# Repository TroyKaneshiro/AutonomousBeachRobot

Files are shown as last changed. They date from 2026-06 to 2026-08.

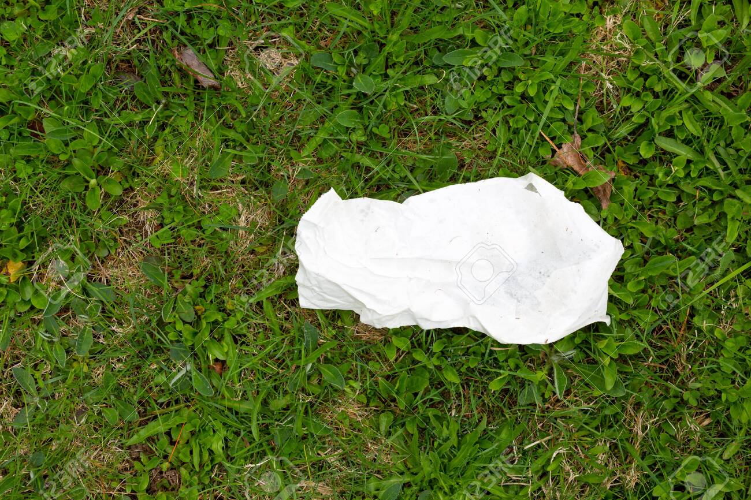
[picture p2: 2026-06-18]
tools/test_trash2.jpg

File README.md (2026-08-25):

# Autonomous Beach Robot

Perception-driven outdoor mobile robot that autonomously detects, tracks, and approaches litter using computer vision and a reactive finite state machine.

Built from scratch with ROS 2 Jazzy, micro-ROS, and custom motor control firmware split across a Raspberry Pi 5 (intelligence) and ESP32 (real-time motor control).

**Current status:** Visual servoing and full FSM state transitions working on hardware. Chassis integration and physical collection mechanism in progress.  
**V2 goal:** Physical trash collection via scoop mechanism, more robust chasis in progress.

---

## System Architecture

### Compute split

| Platform | Role |
|---|---|
| Raspberry Pi 5 (4GB) | ROS 2 Jazzy, YOLOv8n inference, CSRT tracking, mission FSM, GPS logging |
| ESP32 (micro-ROS) | PID motor control at 100Hz on Core 1; encoder odometry on Core 0 |

The Pi decides what to do. The ESP32 executes it with no OS jitter.

### ROS 2 node graph

```
/camera/image_raw ──┬──▶ trash_detector ──▶ /trash_detections ──▶ mission_fsm ──▶ /cmd_vel ──▶ ESP32
                    └──▶ terrain_monitor ──▶ /terrain_events   ──▶ mission_fsm
/wheel/odometry ────────────────────────────────────────────────────────────────▶ mission_fsm
/imu/data ──────────────────────────────────────────────────────────────────────▶ terrain_monitor
/fix (GPS) ──────────────────────────────────────────────────────────────────────▶ mission_fsm
                                                          coordinator ───────────▶ /e_stop ──▶ ESP32
```

---

## Perception Pipeline

**YOLO + CSRT hybrid** — balances detection accuracy with compute budget on Pi 5:

- YOLOv8n runs at ~10 FPS for detection and target selection
- CSRT correlation filter tracks at 30+ FPS between YOLO cycles
- When CSRT loses the target, YOLO re-acquires on the next cycle

**Target scoring** when multiple detections exist:

```python
score = (0.7 * normalised_bbox_area) + (0.3 * confidence)
```

Proximity-weighted: closest target preferred, confidence as tiebreaker.

**Model:** YOLOv8n fine-tuned on [TACO dataset](http://tacodataset.org/) (Trash Annotations in Context), single class `trash`. ONNX export for CPU inference. Current validation **mAP50: 0.549**.

---

## Navigation

**Visual servoing** — no depth sensor, no coordinate transforms:

```python
pixel_error = bbox_centre_x - frame_width / 2
angular_z   = -Kp * pixel_error    # Kp ≈ 0.002
linear_x    = 0.2                  # m/s approach speed
```

Distance inferred from bounding box area growth. Calibrate `pickup_area_threshold` once at physical pickup distance.

**Terrain safety — three independent layers:**

| Layer | Sensor | Detects | Blind spots |
|---|---|---|---|
| Primary | Camera HSV (bottom ⅓ of frame) | Sand→grass, sand→pavement boundaries | Dropoffs, night, glare |
| Backstop | MPU-6050 IMU (pitch + variance) | Dropoffs, vibration spikes, soft sand | Gradual colour-only transitions |
| Backstop | ACS712 current sensors | Motor stall, high-resistance terrain | Airborne obstacles |

---

## Mission FSM

| State | Entry | Behaviour | Exit |
|---|---|---|---|
| CALIBRATE | Startup | Hold still 1.5s; IMU baseline lock | Baseline set → SCAN |
| SCAN | Post-calibrate / post-flag | Rotate 0.3 rad/s; YOLO every 0.5s | Detection conf ≥ 0.45 → TRACK |
| TRACK | Detection acquired | CSRT tracking + visual servoing forward | bbox area ≥ threshold → PICKUP; timeout → SCAN |
| PICKUP | Close enough | V1: log GPS + confidence to CSV, reset tracker. V2: actuate collection mechanism | Complete → SCAN |
| STUCK | No odometry movement for 5s despite cmd_vel | Reverse 0.3m, rotate 45°, resume prior state | Movement detected → prior state |
| LOW_BATTERY | Voltage < 10.5V (3S cutoff) | Stop all motion | Manual operator reset |

---

## ESP32 Firmware

The ESP32 runs custom firmware with:

- **PID motor control at 100Hz** on Core 1 — differential drive kinematics, closed-loop velocity control from encoder feedback
- **micro-ROS bridge** on Core 0 — subscribes to `/cmd_vel` and `/e_stop`, publishes `/wheel/odometry` and `/motor_events`
- **Safety watchdog** — automatically stops motors if no `/cmd_vel` received for 1 second
- **Quadrature encoder odometry** — left and right wheel position and velocity

### Pin assignments

| Signal | GPIO |
|---|---|
| Left Motor PWM | 25 |
| Left Motor DIR | 26 |
| Right Motor PWM | 27 |
| Right Motor DIR | 14 |
| Left Encoder A | 32 |
| Left Encoder B | 33 |
| Right Encoder A | 23 |
| Right Encoder B | 22 |

---

## Hardware Stack

| Component | Role |
|---|---|
| Raspberry Pi 5 (4GB) | Main compute |
| ESP32 DevKit C | Real-time motor control, micro-ROS |
| Cytron MDD10A | Dual motor driver (10A/ch, 3.3V logic native) |
| 4× 12V DC gear motors w/ encoders (JGA25-370) | Locomotion + odometry |
| HD USB Webcam | Trash detection + terrain classification |
| MPU-6050 IMU | Terrain safety |
| u-blox NEO-M8N GPS | Detection coordinate logging |
| ACS712 30A ×2 | Per-motor current sensing |
| 3S LiPo 5000mAh | Main power |

---

## Repository Structure

```
ros2_ws/src/
├── perception/           # trash_detector (YOLO+CSRT) and terrain_monitor nodes
├── v1_navigator/         # mission_fsm — 6-state FSM, visual servoing, GPS CSV logging
├── mission_control/      # coordinator — operator interface, e-stop, 1Hz telemetry
└── robot_bringup/        # launch files and robot_params.yaml

esp32/
└── src/main.cpp          # ESP32 firmware — PID motor control + micro-ROS

ml/
├── convert.py            # TACO COCO→YOLO format converter (80/20 train/val split)
├── trash.yaml            # YOLOv8 dataset config
└── models/               # Trained ONNX weights (Git LFS)

tools/
├── fake_camera.py        # Publishes static image as /camera/image_raw at 30fps
├── fake_hardware.py      # Stubs /wheel/odometry, /imu/data, /fix, /battery_voltage
├── stream_camera.py      # MJPEG HTTP stream for viewing camera feed over network
└── model_tester.py       # Standalone YOLO inference check without ROS

docs/
└── beach_robot_spec_v2.md  # Full system specification with V2 plans
```

---

## Hardware-less Simulation

The full ROS 2 pipeline runs without physical hardware:

```bash
# Terminal 1 — launch in sim mode
ros2 launch robot_bringup sim.launch.py image_path:=/path/to/trash.jpg

# Terminal 2 — arm the robot
ros2 topic pub --once /mission_control/command std_msgs/msg/String "data: START"

# Monitor state
ros2 topic echo /mission_status

# Emergency stop
ros2 topic pub --once /mission_control/command std_msgs/msg/String "data: STOP"
```

---

## Live Camera Stream

To view the camera feed over the network during field testing:

```bash
python3 tools/stream_camera.py
```

Open `http://beachrobot.local:8080` in a browser. Displays live feed with detection bounding boxes overlaid.

---

## V1 vs V2

| Feature | V1 — current | V2 — planned |
|---|---|---|
| Navigation | Reactive visual servoing | Nav2 + EKF + GPS area coverage |
| Detection | YOLOv8n + CSRT | Same, improved dataset |
| Distance | Bounding box area heuristic | Monocular depth or OAK-D stereo |
| Collection | GPS coordinate logging | Servo gripper arm or scoop mechanism |
| Coverage | Scan-navigate-scan | Lawnmower path planning |

---

## Known Limitations

- CSRT tracker loses target under fast motion or significant viewpoint change — re-acquired by YOLO on next cycle
- Confidence threshold (0.45) tuned for outdoor daylight — performance degrades in low light
- Single encoder odometry on current breadboard build — both encoders to be added on perfboard
- No ROS timestamp sync on ESP32 in current build — STUCK watchdog uses position delta rather than message age

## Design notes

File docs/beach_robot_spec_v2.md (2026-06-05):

  
**Beach Trash Collection Robot**

Project Specification  ·  v2

EE/CS \+ MechE/ECE  ·  Summer Build

*Autonomous outdoor robot that scans for litter, tracks and approaches the highest-priority target, and logs GPS coordinates for collection — with a robotic arm pickup system as the v2 goal.*

# **1\. Project overview**

This robot patrols a beach or open field autonomously, uses computer vision to detect and track litter, and drives toward the highest-priority piece of trash. V1 logs GPS coordinates of detections. V2 adds a robotic arm for physical collection.

## **1.1 Core behaviour loop**

* SCAN — robot rotates 360°, YOLOv8n identifies all visible trash, scores each detection by proximity and confidence

* TRACK — CSRT visual tracker locks onto the best target, robot steers toward it using visual servoing

* APPROACH — bounding box area grows as robot closes in; no explicit distance measurement needed

* FLAG / PICKUP — at threshold bbox size: V1 logs GPS coordinate; V2 actuates gripper arm

* SCAN again — repeat until battery low or operator stop

*Design principle: the robot is perception-driven — every movement decision comes from what the camera sees, not a pre-planned path. This makes behaviour more robust and the project significantly more impressive as a portfolio piece.*

## **1.2 V1 vs V2 scope**

| Feature | V1 — ship by end of summer | V2 — stretch / fall |
| :---- | :---- | :---- |
| Navigation | Reactive — IMU \+ camera terrain boundary | Nav2 \+ EKF \+ GPS positioning |
| Target detection | YOLOv8n scan \+ CSRT tracking | Same, improved dataset |
| Distance sensing | Bounding box area heuristic | Monocular depth or OAK-D |
| Trash collection | GPS flag and log | Servo gripper arm pickup |
| Coverage | Scan-navigate-scan | Lawnmower path planning |
| Localisation | None required | Odometry \+ IMU \+ GPS EKF fusion |

# **2\. Team & responsibility split**

| Domain | EE/CS | MechE/ECE partner |
| :---- | :---- | :---- |
| Chassis & drivetrain | — | CAD design, 3D-printed mounts, assembly |
| Motor control firmware | Serial protocol, ROS bridge | PID loop on ESP32 |
| Power system | Wiring, buck converter, fusing, LiPo safety | Cable routing through chassis |
| Sensors | IMU, GPS, camera wiring and drivers | Encoder wiring, current sensor placement |
| Perception | YOLOv8 training, CSRT node, terrain classifier | Camera mounting, FOV optimisation |
| Navigation FSM | Mission state machine, visual servoing | Odometry calibration, field testing |
| Integration | ROS node graph, launch files, logging | Mechanical fixes, sand-proofing |
| V2 arm (stretch) | PCA9685 servo driver, arm ROS node | Gripper mechanism design and fabrication |

# **3\. System architecture**

## **3.1 Hardware layers**

The system is split across two compute platforms with a clean interface between them.

| Layer | Hardware | Responsibility |
| :---- | :---- | :---- |
| Brain | Raspberry Pi 5 (4GB) | ROS 2, YOLOv8 inference, CSRT tracker, mission FSM, GPS logging |
| Muscles | ESP32 DevKit C | PID motor control at 100Hz, encoder counting, current sensing, micro-ROS bridge |
| Drive | Cytron MDD10A \+ 4× 12V DC gear motors | Locomotion — converts PWM signals to motor power |
| Vision | Pi Camera Module 3 (wide angle) | Single shared feed for trash detection and terrain classification |
| Orientation | MPU-6050 IMU | Safety layer — pitch and vibration spike detection for terrain boundaries and dropoffs |
| Location | u-blox NEO-M8N GPS | Logs coordinates of every detected trash item at 5Hz |
| Current sense | ACS712 30A ×2 | Per-motor current monitoring — detects stall and terrain resistance changes |
| Power | 3S LiPo 5000mAh \+ buck converter 12V→5V | Isolated rails for motors and compute; LiPo alarm on balance lead |
| V2: Arm driver | PCA9685 servo driver board | Controls gripper arm servos from Pi over I2C |

## **3.2 ROS 2 topic map**

| Topic | Message type | Publisher | Subscriber(s) |
| :---- | :---- | :---- | :---- |
| /camera/image\_raw | sensor\_msgs/Image | v4l2\_camera\_node | perception, terrain\_monitor |
| /trash\_detections | std\_msgs/String | trash\_detector | mission\_fsm |
| /terrain\_events | std\_msgs/String | terrain\_monitor | mission\_fsm |
| /motor\_events | std\_msgs/String | ESP32 | mission\_fsm |
| /cmd\_vel | geometry\_msgs/Twist | mission\_fsm / navigator | ESP32 |
| /wheel/odometry | nav\_msgs/Odometry | ESP32 | mission\_fsm (V2: EKF) |
| /imu/data | sensor\_msgs/Imu | mpu6050\_driver | terrain\_monitor |
| /fix | sensor\_msgs/NavSatFix | ublox\_gps\_node | gps\_logger |
| /battery\_voltage | std\_msgs/Float32 | ESP32 | mission\_fsm |

## **3.3 Mission FSM**

All navigation and task behaviour lives in a single finite state machine node. States are mutually exclusive; transitions are event-driven.

| State | Entry condition | Behaviour | Exit condition |
| :---- | :---- | :---- | :---- |
| CALIBRATE | Startup | Hold still, establish IMU baseline variance over 1.5s | Baseline locked → SCAN |
| SCAN | After CALIBRATE, FLAG, or PICKUP | Rotate slowly at 0.3 rad/s, run YOLO every 0.5s, score all detections | Detection above threshold → TRACK |
| TRACK | Detection scored and selected | CSRT locks on target, visual servoing steers robot toward it | Bbox area \> threshold → PICKUP; target lost → SCAN |
| PICKUP / FLAG | Close enough to target | V1: log GPS \+ confidence to CSV. V2: stop, actuate arm | Attempt complete → SCAN |
| STUCK | No movement for 5s despite cmd\_vel | Reverse 0.3m, rotate 45°, resume prior state | Movement detected → resume |
| LOW\_BATTERY | Voltage \< 10.5V (3S cutoff) | Stop all motion, publish alert, await operator | Manual reset only |

# **4\. Perception pipeline**

## **4.1 Trash detection — YOLOv8n**

* Model: YOLOv8 nano (yolov8n.pt), fine-tuned on TACO dataset (Trash Annotations in Context)

* Classes: collapsed to single class 'trash' for v1 — simplifies training, sufficient for detection

* Export format: ONNX, imgsz=640, simplified

* Target inference rate: 8–15 FPS on Pi 5 with active cooling

* Target mAP50: \> 0.40 on validation set

## **4.2 Target selection scoring**

When multiple detections exist, a weighted score selects the best target per frame:

score \= (0.7 × normalised\_bbox\_area) \+ (0.3 × confidence)

* Proximity weight 0.7 — closest target preferred; bbox area is proxy for distance

* Confidence weight 0.3 — avoids wasting approach on false positives

* Blacklist — targets that fail pickup twice are excluded from scoring until next full scan

* Re-score every 2s during TRACK — relative distances change as robot moves

## **4.3 CSRT visual tracking**

After YOLO selects a target, a CSRT tracker (OpenCV built-in) takes over for per-frame localisation. YOLO runs at 8–10 FPS; CSRT runs at 30+ FPS on the same detection region without re-running the neural net.

* Init: tracker.init(frame, bbox) called once after YOLO detection

* Update: ok, bbox \= tracker.update(frame) every frame

* Lost: if ok is False → fall back to SCAN state to re-acquire

* Proximity trigger: bbox\_area / frame\_area \> PICKUP\_THRESHOLD (calibrate at your actual pickup distance)

## **4.4 Terrain classification**

A lightweight secondary perception node subscribes to the same camera feed and publishes STOP\_CAM events when the terrain ahead changes. The camera is a secondary signal; the IMU is the safety backstop.

* Method: HSV colour thresholding on bottom third of frame

* Trigger: sand\_ratio \< 0.5 in the ROI

* Rate: throttled to 10 FPS to leave headroom for YOLO

* Tuning: HSV range must be calibrated at the actual test location in the actual lighting conditions

*Camera terrain classification catches visual boundaries (sand/grass, sand/pavement). IMU catches physical events (dropoffs, vibration spikes, soft sand sinking). They fail on different inputs — both are needed.*

# **5\. Navigation & motor control**

## **5.1 Visual servoing**

The robot steers toward a tracked target using proportional control on the horizontal offset of the bounding box centre from the frame centre. No distance measurement, no coordinate frame transformation needed.

error \= bbox\_centre\_x − frame\_width/2angular\_z \= −Kp × error   (Kp ≈ 0.002, tune empirically)linear\_x \= APPROACH\_SPEED (0.2 m/s)

## **5.2 Motor control (ESP32)**

* PID loop runs at 100Hz on ESP32 Core 1 — real-time, no OS jitter

* Core 0 handles micro-ROS WiFi/serial comms — physically isolated from PID

* Per-motor PID — each motor has independent Kp/Ki/Kd; motors are never identical

* ACS712 current sensors publish HIGH\_CURRENT events when average exceeds 2.5A per motor

* Encoder odometry published to /wheel/odometry at 50Hz

## **5.3 Terrain safety — dual-layer**

| Layer | Sensor | Catches | Misses |
| :---- | :---- | :---- | :---- |
| Primary | Camera HSV classifier | Visual boundaries: sand→grass, sand→pavement | Dropoffs, soft sand, glare, night |
| Safety backstop | MPU-6050 IMU | Dropoffs, vibration spikes, pitch \> 8.5°, soft sand sinking | Gradual colour-only boundaries |
| Safety backstop | ACS712 current sensors | Motor stall, high resistance terrain, wheel sinking | Airborne obstacles, visual changes |

# **6\. Hardware bill of materials**

## **6.1 Compute & firmware**

| Component | Purpose | Cost | Notes |
| :---- | :---- | :---- | :---- |
| Raspberry Pi 5 (4GB) | Main compute, ROS 2, inference | $60 | Order immediately — can be backordered |
| Pi 5 active cooler | Thermal management under inference load | $5 | Required — YOLOv8 will throttle without it |
| ESP32 DevKit C ×2 | Real-time motor PID, micro-ROS | $16 | Buy two — one will get bricked in dev |
| MicroSD 64GB A2-rated | Pi OS \+ ROS workspace \+ rosbag logs | $10 | A2 speed class required for ROS I/O |

## **6.2 Chassis & drivetrain**

| Component | Purpose | Cost | Notes |
| :---- | :---- | :---- | :---- |
| 4WD aluminium chassis kit | Frame, mounts, hubs | $45 | Get one that includes motors \+ encoders |
| 12V DC gear motors ×4 with encoders | Locomotion \+ odometry feedback | Included | Verify \> 200 CPR encoder resolution |
| Wide rubber wheels ×4 | Traction on sand and grass | Included | Wide profile preferred; avoid narrow plastic |
| M3/M4 hardware assortment | Electronics mounting | $8 | Standoffs, screws, nuts — use everything |

## **6.3 Motor driver**

| Component | Purpose | Cost | Notes |
| :---- | :---- | :---- | :---- |
| Cytron MDD10A (recommended) | Dual motor driver, 10A/ch, 3.3V safe | $25 | MOSFET-based, no heatsink, ESP32 native logic |
| L298N (budget alternative) | Dual motor driver, 2A/ch | $4 | Add heatsink \+ logic level shifter; buy 2 as spares |
| Logic level shifter (if L298N) | 3.3V→5V for ESP32→L298N | $1 | Only needed with L298N |

## **6.4 Sensors**

| Component | Purpose | Cost | Notes |
| :---- | :---- | :---- | :---- |
| Pi Camera Module 3 Wide | Trash detection \+ terrain classifier | $25 | Wide angle; order immediately with Pi |
| MPU-6050 IMU | Terrain safety: pitch, vibration spike | $5 | Mount on 1mm foam tape away from motors |
| ACS712 30A current sensors ×2 | Per-motor stall and terrain detection | $6 | Inline with each motor lead |
| u-blox NEO-M8N GPS | Logs trash detection coordinates | $30 | Configure at 5Hz via u-center before deployment |
| Camera mount / articulating arm | Positions camera \~30° down at 0.5m | $8 | Can 3D print a custom mount |

## **6.5 Power system**

| Component | Purpose | Cost | Notes |
| :---- | :---- | :---- | :---- |
| 3S LiPo 5000mAh (Tattu / Gens Ace) | Main power source | $35 | Quality brand only; check C-rating ≥ 20C |
| LiPo battery alarm | Per-cell undervoltage alert at 3.5V | $3 | Non-negotiable safety item |
| LiPo balance charger (ISDT Q6) | Safe balanced charging | $25 | Never charge without a balance charger |
| LiPo safe bag | Fire containment during charging | $8 | Always charge in this bag |
| Buck converter 12V→5V 5A | Regulated 5V for Pi and sensors | $8 | Pololu D24V50F5 is reliable; verify 5.1V output |
| XT60 connector pairs ×5 | Battery main lead | $6 | Standard 60A+ rated; solder properly |
| 20A blade fuse \+ holder | Main line protection | $4 | Inline on battery positive; saves the chassis |

## **6.6 Wiring & consumables**

| Component | Purpose | Cost |
| :---- | :---- | :---- |
| Silicone wire 18AWG red/black 5m ea | Motor and power runs | $10 |
| Jumper wire kit (M-M, M-F, F-F) | Sensor connections and prototyping | $7 |
| JST-XH 2.54mm connector kit | Encoder and sensor wire management | $8 |
| Heat shrink tubing assortment | Insulation on all solder joints | $5 |
| 1mm foam mounting tape | IMU vibration damping | $4 |
| Velcro straps | Battery retention and cable routing | $5 |
| Conformal coat spray | Board protection against sand and moisture | $12 |

## **6.7 V2 additions (arm)**

| Component | Purpose | Cost | Notes |
| :---- | :---- | :---- | :---- |
| PCA9685 servo driver board | Controls arm servos from Pi over I2C | $8 | 16-channel; only needs 3–4 for a simple arm |
| Servo gripper arm kit (2–3 DOF) | Physical trash pickup | $40–60 | Your partner's mechanical design domain |
| High-torque servos ×3 (MG996R) | Arm joints and gripper | Included or \~$20 | Sand-rated or enclose them |

## **6.8 Budget summary**

| Build variant | Estimated total |
| :---- | :---- |
| V1 — Cytron MDD10A (recommended) | \~$300–340 |
| V1 — L298N (budget) | \~$275–315 |
| V2 — add arm components | \+ \~$70–90 |

# **7\. Software stack**

## **7.1 Environment**

| Component | Version / detail |
| :---- | :---- |
| OS | Raspberry Pi OS 64-bit (Bookworm) |
| ROS 2 | Humble Hawksbill (LTS) |
| Python | 3.10+ |
| ESP32 framework | micro-ROS \+ Arduino via PlatformIO |
| ML inference | Ultralytics YOLOv8, ONNX runtime |
| Vision | OpenCV 4.x (CSRT tracker built-in) |
| Training | Google Colab T4 GPU, YOLOv8n.pt pretrained |
| Dataset | TACO (Trash Annotations in Context), collapsed to 1 class |

## **7.2 Repository structure**

* firmware/esp32/ — PlatformIO project: PID, encoder, current sense, micro-ROS

* ros2\_ws/src/v1\_navigator/ — mission FSM, visual servoing, STUCK/LOW\_BATTERY states

* ros2\_ws/src/perception/ — trash\_detector node (YOLOv8 \+ CSRT) and terrain\_monitor node

* ros2\_ws/src/mission\_control/ — high-level state coordinator

* ros2\_ws/src/robot\_bringup/ — launch files, YAML configs

* ml/ — training script, trash.yaml, exported models (gitignored if \> 100MB)

* docs/ — wiring diagram PDF, serial protocol spec, field tuning notes

## **7.3 Key design decisions**

* One camera, two consumers — camera node publishes /camera/image\_raw once; both perception nodes subscribe and throttle themselves independently. Never open the camera device from two nodes.

* ESP32 owns real-time, Pi owns intelligence — PID loop on ESP32 Core 1 at 100Hz with no OS interruption. Pi decides what to do; ESP32 executes it precisely.

* CSRT over YOLO for tracking — YOLO detects once, CSRT tracks at 30+ FPS. Hybrid approach gives accuracy without burning all compute budget on inference.

* Bounding box area as distance proxy — elegant, hardware-free, calibrated once at actual pickup distance. No depth camera required for V1.

* IMU as safety backstop only — camera terrain classification is primary; IMU is the last-resort emergency brake for physical events the camera cannot see.

# **8\. 10-week build timeline**

## **EE/CS track (your responsibilities)**

| Week | Phase | Your deliverables |
| :---- | :---- | :---- |
| 1 | Setup | Pi OS \+ ROS 2 installed, ESP32 \+ micro-ROS ping-pong, repo scaffold, protocol doc, power bench test, parts ordered |
| 2 | Drive | ESP32 firmware: /cmd\_vel → PID → motors; /wheel/odometry from encoders; ACS712 current sensing wired and publishing |
| 3 | Sensors | IMU terrain detection node live; camera feed publishing; terrain\_monitor combining IMU \+ camera signals |
| 4 | Navigate | Mission FSM: CALIBRATE → SCAN → TRACK → FLAG; visual servoing proportional controller tuned on bench |
| 5 | ML | YOLOv8n trained on TACO, ONNX exported, benchmarked on Pi at ≥ 8 FPS, ROS perception node publishing /trash\_detections |
| 6 | Integrate | CSRT tracker integrated; full pipeline: camera → detect → track → approach → flag; GPS wired and logging |
| 7 | Test | First outdoor test; re-tune IMU baseline, HSV range, current thresholds at actual beach/field location |
| 8 | Harden | STUCK \+ LOW\_BATTERY states; rosbag logging every run; edge case handling (glare, wet sand, GPS loss) |
| 9 | Polish | Post-run visualisation: plot GPS detection pins on map; 2× clean outdoor runs recorded; repo cleaned up |
| 10 | Demo | Final demo video, README writeup, ML pipeline documented, tag v1.0 |

## **Milestones**

| Week | Milestone |
| :---- | :---- |
| End week 2 | Robot drives and stops on /cmd\_vel command |
| End week 4 | Robot scans, detects trash in camera feed, visual servoing steers toward it on a table |
| End week 6 | Full pipeline running: scan → track → approach → GPS log |
| End week 8 | 10-minute autonomous outdoor run without intervention |
| End week 10 | Portfolio-ready project with demo video and write-up |

# **9\. Engineering notes & lessons**

## **9.1 Sand-specific concerns**

* Conformal coat all PCBs before first outdoor deployment — sand \+ salt air \+ moisture is corrosive

* Enclose Pi and ESP32 in 3D-printed PETG/ASA boxes with rubber-grommeted cable holes

* Mesh or foam over any ventilation holes — sand gets into everything

* Wide-profile rubber wheels only — narrow wheels sink; plastic wheels slip

* Motors will draw more current on sand than in indoor tests — tune current threshold accordingly

* GPS antenna needs clear sky view — test fix quality before full runs (should read position\_covariance\[0\] \< 5.0)

## **9.2 LiPo safety — non-negotiable**

*Always charge in a LiPo bag. Always use a balance charger. Never leave charging unattended. Never discharge below 3.5V/cell. Store at 3.8V/cell if not using for more than a week.*

## **9.3 Power system rules**

* 20A blade fuse inline on main battery positive — $0.50 that protects the chassis

* Motors and Pi on separate regulated rails — motor noise on the Pi supply causes random crashes

* Buck converter must handle 5A+ — Pi 5 draws up to 5A at peak

* Bench-test full power system before connecting Pi: verify 5.0–5.2V output under load

## **9.4 Key principles**

* Ship v1 first — a working simple system beats a broken complex one every time

* Record everything — rosbag every outdoor session; you debug from logs, not memory

* Tune at the real location — indoor calibration is always wrong outdoors

* Weekly sync with partner — explicit agenda, written deliverables; assumptions cause failures

* Document as you go — commits with meaning, photos at each milestone, video at each working demo

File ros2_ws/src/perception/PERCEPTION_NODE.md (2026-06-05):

# Perception Node — Implementation Brief
> Context file for Claude Code. Write this node from scratch based on the spec below.

---

## What this node does

Subscribes to the robot's camera feed, runs YOLOv8n trash detection on each frame, tracks the best target using OpenCV CSRT, and publishes the result for the mission FSM to act on.

Two classes live in this file:
- `TrashDetector` — the ROS 2 node
- Internal CSRT tracker state managed within the node

---

## File location

```
AutonomousBeachRobot/
└── ros2_ws/
    └── src/
        └── perception/
            └── perception/
                └── trash_detector.py   ← write this file
```

---

## ROS 2 interface

### Subscribes to
| Topic | Type | Rate | Notes |
|---|---|---|---|
| `/camera/image_raw` | `sensor_msgs/Image` | 30Hz | Throttle internally to 10fps for YOLO |

### Publishes to
| Topic | Type | Notes |
|---|---|---|
| `/trash_detections` | `std_msgs/String` | JSON string, only published when detection exists |

### Published message format
```json
{
  "cx": 320.5,
  "cy": 410.2,
  "area": 14500,
  "conf": 0.82,
  "tracking": true,
  "bbox": [280, 390, 361, 431]
}
```
- `cx`, `cy` — bounding box centre in pixels
- `area` — bounding box area in pixels (proxy for distance — bigger = closer)
- `conf` — YOLO confidence score 0.0–1.0
- `tracking` — true if CSRT tracker is active, false if fresh YOLO detection
- `bbox` — [x1, y1, x2, y2] pixel coordinates

---

## Detection pipeline

```
Camera frame arrives
        │
        ├── [every frame]  CSRT tracker update (30fps)
        │         │
        │         ├── ok=True  → publish tracker result
        │         └── ok=False → tracker lost, fall back to YOLO
        │
        └── [every 0.1s]   YOLO inference (10fps)
                  │
                  ├── detections found → score them → init CSRT on best
                  └── no detections    → publish nothing
```

Key design: YOLO runs at 10fps (expensive), CSRT runs every frame (cheap). When CSRT loses the target, YOLO re-acquires it.

---

## Target scoring

When YOLO finds multiple detections, pick the best one using:

```python
score = (0.7 * normalised_area) + (0.3 * confidence)

# normalised_area = bbox_area / (frame_width * frame_height)
# confidence is already 0.0–1.0
```

Highest score wins. This prioritises the closest trash (biggest bbox) with confidence as a tiebreaker.

---

## CSRT tracker behaviour

```python
# Initialise tracker after a fresh YOLO detection
tracker = cv2.TrackerCSRT_create()
tracker.init(frame, (x, y, w, h))   # bbox as x,y,w,h not x1,y1,x2,y2

# Update every frame
ok, bbox = tracker.update(frame)
# ok=False means lost — set tracker to None, wait for next YOLO cycle
```

Re-initialise the tracker whenever YOLO finds a new higher-scoring target.

---

## Parameters

| Parameter | Default | Notes |
|---|---|---|
| `model_path` | `'models/trash_v1_best.onnx'` | Path to ONNX model file |
| `confidence_threshold` | `0.45` | Ignore YOLO detections below this |
| `yolo_interval` | `0.1` | Seconds between YOLO inference calls |
| `frame_width` | `640` | Expected camera frame width |
| `frame_height` | `480` | Expected camera frame height |

Declare these as ROS 2 parameters so they can be overridden from the launch file without editing code:
```python
self.declare_parameter('confidence_threshold', 0.45)
conf = self.get_parameter('confidence_threshold').value
```

---

## Key imports

```python
import rclpy
from rclpy.node import Node
from sensor_msgs.msg import Image
from std_msgs.msg import String
from cv_bridge import CvBridge
from ultralytics import YOLO
import cv2
import numpy as np
import json
import time
```

---

## Node skeleton

```python
class TrashDetector(Node):
    def __init__(self):
        super().__init__('trash_detector')

        # Parameters
        # Model loading
        # Publisher + Subscriber
        # CSRT tracker state
        # Timing for YOLO throttle

    def image_callback(self, msg):
        # Convert ROS image to OpenCV frame using CvBridge
        # Run CSRT update every frame
        # Run YOLO every self.yolo_interval seconds
        # Score detections, pick best
        # Re-init CSRT if new best target found
        # Publish result

    def run_yolo(self, frame):
        # Run YOLO inference
        # Filter by confidence threshold
        # Score each detection
        # Return best detection or None

    def score_detection(self, bbox, confidence):
        # score = 0.7 * normalised_area + 0.3 * confidence
        # Return float score

    def publish_detection(self, bbox, confidence, tracking):
        # Build JSON dict
        # Publish as std_msgs/String

def main():
    rclpy.init()
    node = TrashDetector()
    rclpy.spin(node)
    rclpy.shutdown()
```

---

## setup.py entry point

Make sure this line exists in the `console_scripts` section of
`ros2_ws/src/perception/setup.py`:

```python
'trash_detector = perception.trash_detector:main',
```

Without this, `ros2 run perception trash_detector` won't find the node.

---

## package.xml dependencies

Add these to `ros2_ws/src/perception/package.xml` inside `<package>`:

```xml
<depend>rclpy</depend>
<depend>sensor_msgs</depend>
<depend>std_msgs</depend>
<depend>cv_bridge</depend>
```

---

## Testing without a camera

You can test this node before the Pi or camera arrives by publishing a fake image topic from a static file:

```bash
# Terminal 1 — run the node
ros2 run perception trash_detector

# Terminal 2 — feed it a static image as a ROS topic
# Install: pip3 install ros2-numpy
python3 -c "
import rclpy
from rclpy.node import Node
from sensor_msgs.msg import Image
from cv_bridge import CvBridge
import cv2

rclpy.init()
node = Node('fake_camera')
pub = node.create_publisher(Image, '/camera/image_raw', 10)
bridge = CvBridge()
img = cv2.imread('path/to/trash_image.jpg')
img = cv2.resize(img, (640, 480))
msg = bridge.cv2_to_imgmsg(img, encoding='bgr8')

timer = node.create_timer(0.033, lambda: pub.publish(msg))
rclpy.spin(node)
"

# Terminal 3 — watch detections
ros2 topic echo /trash_detections
```

Use any JPEG of trash — a photo from your phone, a Google image, anything.

---

## Common mistakes to avoid

- **Don't open the camera device directly** (`cv2.VideoCapture`) — subscribe to `/camera/image_raw` instead. Other nodes share this feed.
- **Don't forget CvBridge** — ROS image messages and OpenCV frames are different formats. Always convert with `bridge.imgmsg_to_cv2(msg, 'bgr8')`.
- **CSRT bbox format** — OpenCV trackers use `(x, y, w, h)` not `(x1, y1, x2, y2)`. Convert before passing to `tracker.init()`.
- **Thread safety** — `rclpy.spin()` is single-threaded by default so callbacks won't interrupt each other. No locks needed for v1.
- **Model path** — use an absolute path or a path relative to where you launch the node. Relative paths break depending on where you run `ros2 run` from.

---

## Related nodes (for context)

This node feeds into:
- `mission_fsm.py` (v1_navigator package) — subscribes to `/trash_detections` and decides robot behaviour
- `terrain_monitor.py` (perception package) — sibling node, shares `/camera/image_raw` feed

---

## What success looks like

When working correctly:
```bash
ros2 topic echo /trash_detections
# Should print JSON like:
# data: '{"cx": 318.2, "cy": 405.1, "area": 12400, "conf": 0.76, "tracking": true, "bbox": [...]}'
```

And topic rate should be ~10Hz when trash is visible, silent when frame is clear.

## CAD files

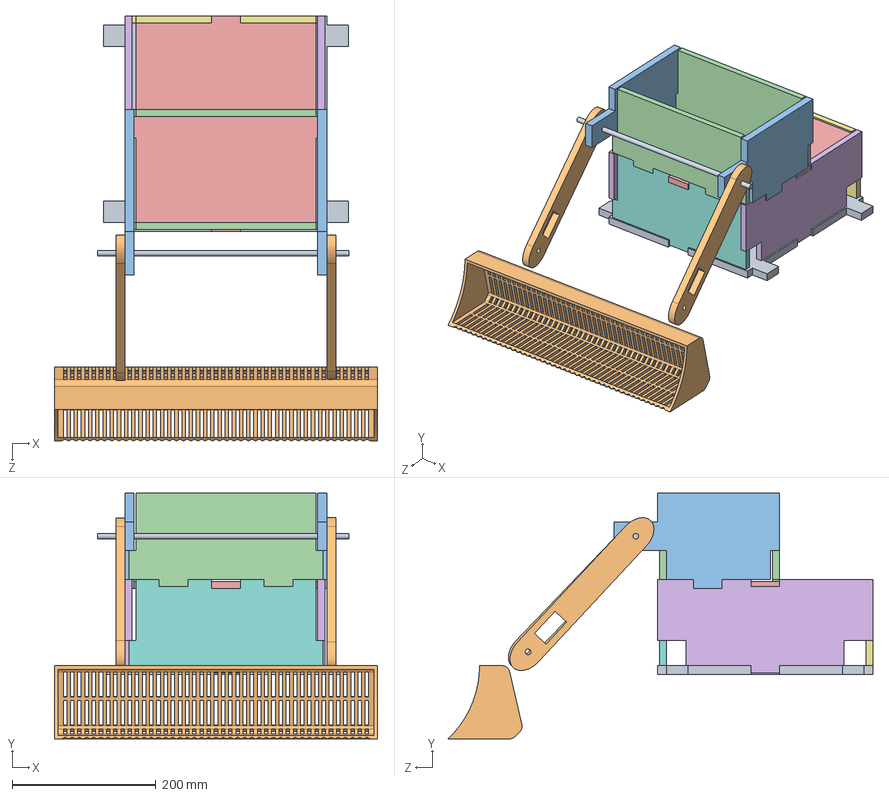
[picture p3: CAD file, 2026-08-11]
hardware/cad/cad_files/rover.SLDASM
450.0 x 342.0 x 591.3 mm
scoop
basePlate
fbPlatesBasket
fbPlates
sidePlate x 2
topPlate
basketFront x 2
basketSide x 2
arm x 2
axle

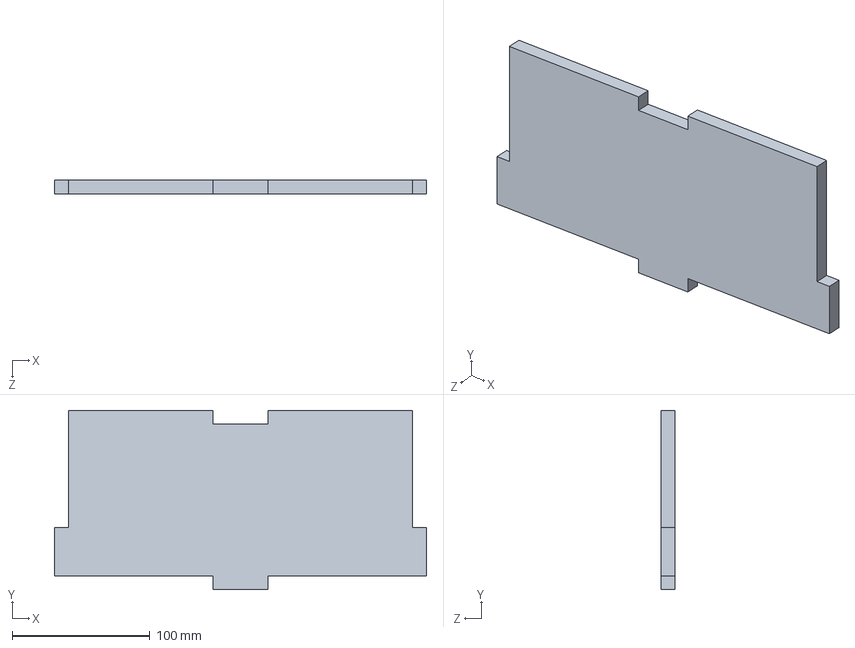
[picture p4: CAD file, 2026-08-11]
hardware/cad/cad_files/fbPlatesBasket.SLDPRT
270.0 x 130.0 x 10.0 mm

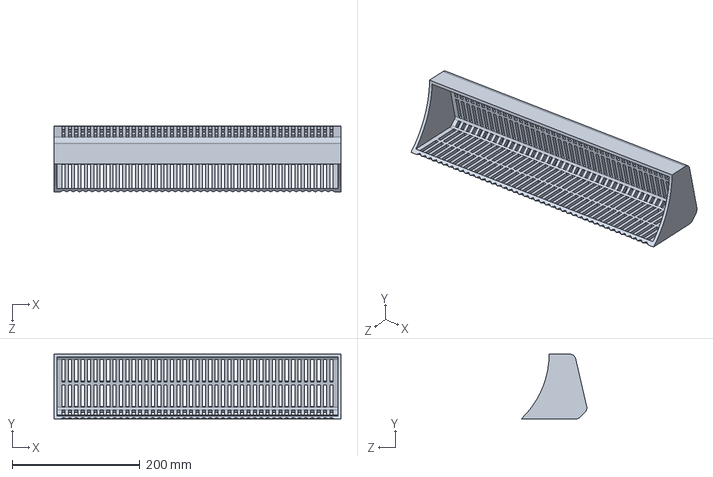
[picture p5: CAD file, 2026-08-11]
hardware/cad/cad_files/scoop.SLDPRT
450.0 x 101.8 x 103.1 mm

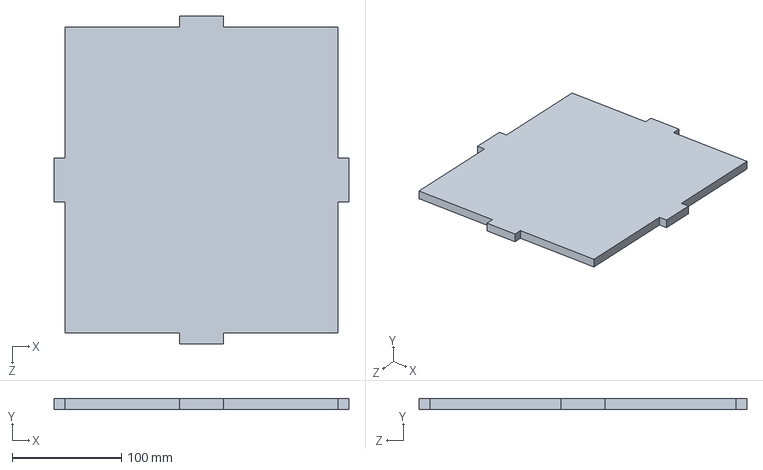
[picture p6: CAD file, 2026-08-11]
hardware/cad/cad_files/topPlate.SLDPRT
270.0 x 10.0 x 300.0 mm

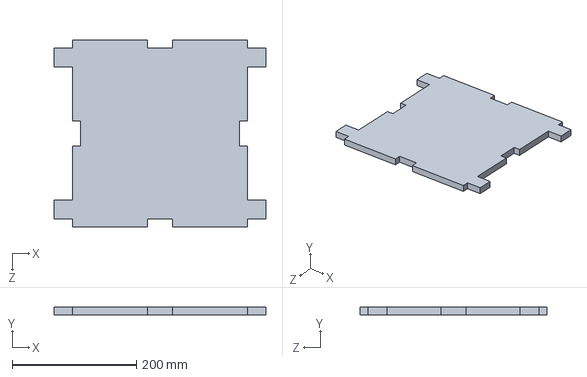
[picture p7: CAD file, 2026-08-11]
hardware/cad/cad_files/basePlate.SLDPRT
340.8 x 12.7 x 300.0 mm

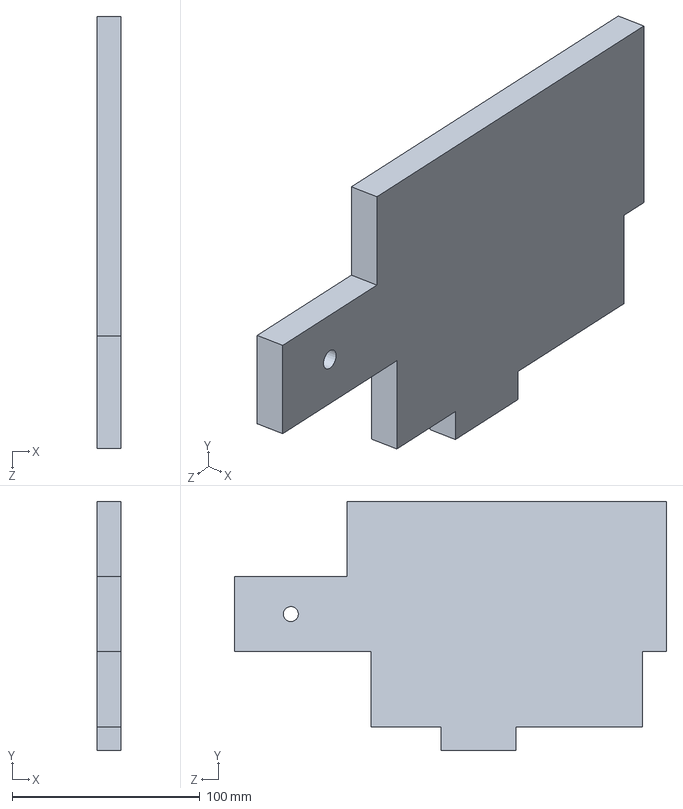
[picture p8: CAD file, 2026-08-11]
hardware/cad/cad_files/basketSide.SLDPRT
12.7 x 132.7 x 230.0 mm

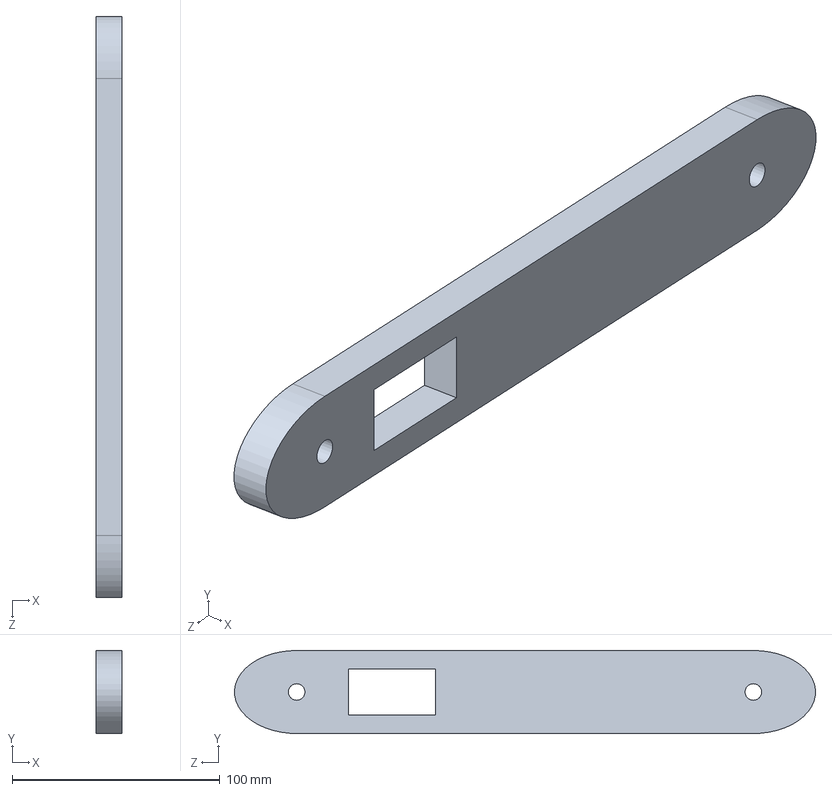
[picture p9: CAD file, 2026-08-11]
hardware/cad/cad_files/arm.SLDPRT
12.7 x 40.0 x 279.9 mm

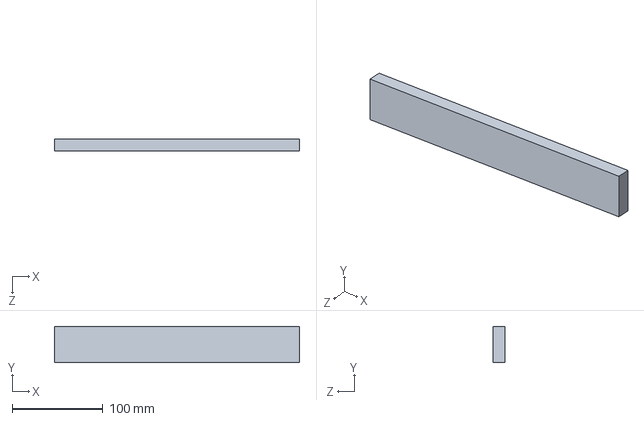
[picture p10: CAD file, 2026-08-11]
hardware/cad/cad_files/bar.SLDPRT
270.0 x 40.0 x 12.7 mm

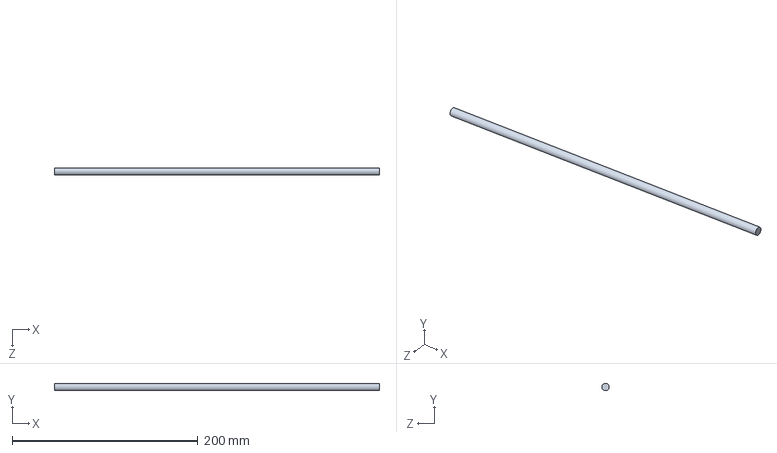
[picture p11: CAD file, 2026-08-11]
hardware/cad/cad_files/axle.SLDPRT
350.0 x 7.98 x 7.97 mm

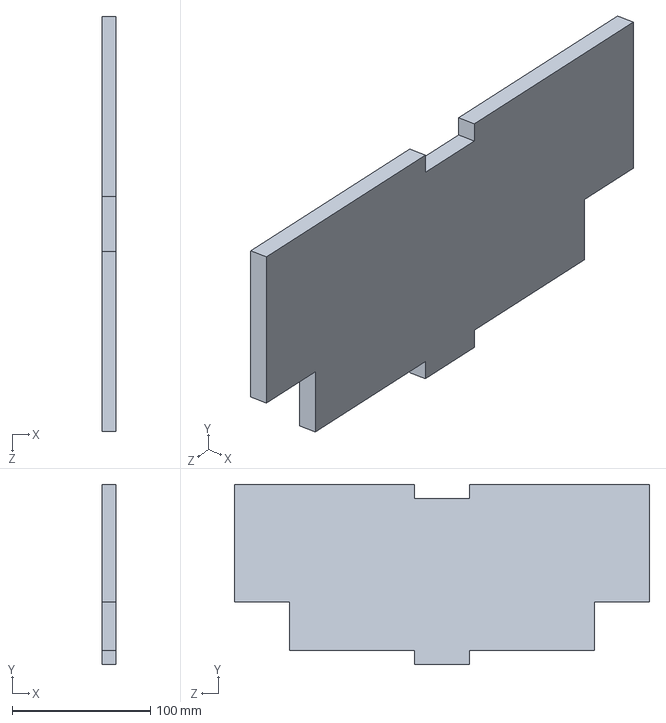
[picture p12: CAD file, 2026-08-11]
hardware/cad/cad_files/sidePlate.SLDPRT
10.0 x 130.0 x 300.0 mm

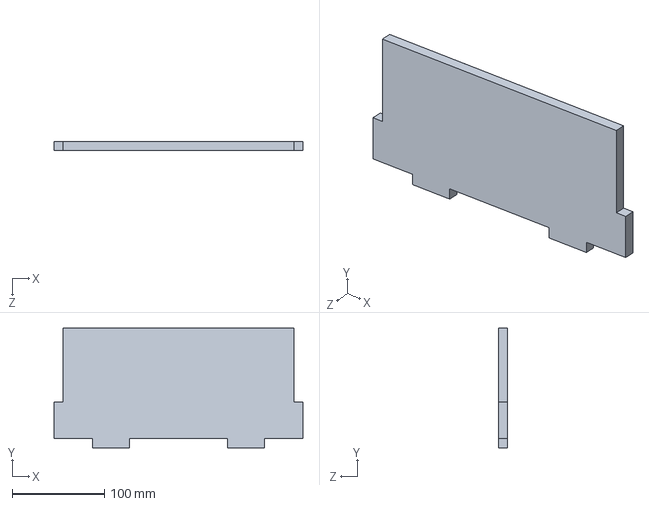
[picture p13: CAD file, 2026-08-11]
hardware/cad/cad_files/basketFront.SLDPRT
270.0 x 130.0 x 10.0 mm

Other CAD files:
hardware/cad/cad_files/fbPlates.SLDPRT

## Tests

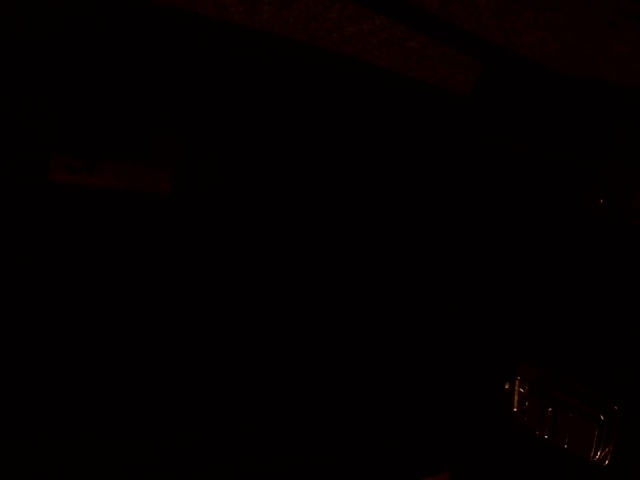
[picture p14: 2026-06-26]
ros2_ws/raw_test.jpg

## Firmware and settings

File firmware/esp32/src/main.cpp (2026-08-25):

#include <micro_ros_arduino.h>
#include <rcl/rcl.h>
#include <rclc/rclc.h>
#include <rclc/executor.h>
#include <geometry_msgs/msg/twist.h>
#include <nav_msgs/msg/odometry.h>
#include <sensor_msgs/msg/imu.h>
#include <sensor_msgs/msg/range.h>
#include <std_msgs/msg/string.h>
#include <Wire.h>
#include <Adafruit_PWMServoDriver.h>
#include <I2Cdev.h>
#include <MPU6050.h>

// ─── HARDWARE CONSTANTS ───
#define WHEEL_RADIUS      0.051f
#define WHEEL_BASE        0.3f
#define TICKS_PER_REV     1664
#define METERS_PER_TICK   (2.0f * M_PI * WHEEL_RADIUS / TICKS_PER_REV)
#define RADS_PER_TICK     (2.0f * M_PI / TICKS_PER_REV)

// ─── PID CONSTANTS (starter values — tune on the bench) ───
// Kp: PWM per (rad/s) error.  Too low → sluggish; too high → oscillation.
// Ki: integrates out steady-state drag/friction offset.
// Kd: set to 0 first; only raise if Kp+Ki loop is stable and you need faster settling.
// INT_LIMIT: caps |Ki·integral| at ±100 PWM so the integrator can't saturate the output.
// TASK_DT:   must match the vTaskDelay period at the bottom of motor_task (10 ms).
#define PID_KP          50.0f
#define PID_KI          20.0f
#define PID_KD           0.5f
#define PID_INT_LIMIT  100.0f
#define MOTOR_TASK_DT    0.01f

// Defined here (before any function signatures) so Arduino auto-prototyping
// doesn't generate a forward declaration for pid_compute before the type exists.
struct PIDState { float integral; float prev_error; };

// ─── PIN DEFINITIONS ───
#define MOTOR_R_PWM   25
#define MOTOR_R_DIR   26
#define MOTOR_L_PWM   27
#define MOTOR_L_DIR   14
#define ENC_R_A       2
#define ENC_R_B       18
#define ENC_L_A       32
#define ENC_L_B       33

// HC-SR04 ultrasonic — front-facing object detection.
// NOTE: GPIO34/35 are input-only on the ESP32 (no output driver), so TRIG
// cannot physically be wired to 35 as originally planned. TRIG moved to the
// free GPIO23; ECHO stays on 34 since input-only is fine for an input pin.
#define ULTRASONIC_TRIG_PIN   15
#define ULTRASONIC_ECHO_PIN   34

// ─── ARM CONSTANTS — placeholders, all TODOs below need real hardware values ───
// Mechanism: one linear actuator lifts the scoop, one servo rotates at the
// top to dump the load backward, then both retract/re-home.
// Actuator is a plain two-wire DC linear actuator (just motor leads, no
// built-in limit switches or position feedback) driven through a PWM+DIR
// H-bridge, same pattern as the drive motors (Cytron-style). Stroke length
// is bounded purely by time (ARM_LIFT_TIME_MS / ARM_LOWER_TIME_MS below) —
// there's no feedback to end the stroke early.
#define ARM_ACT_PWM           12  // linear actuator drive PWM
#define ARM_ACT_DIR           13   // linear actuator direction (HIGH = extend/lift, TODO confirm)

// One shared I2C bus carries both the dump-gate servo driver (PCA9685) and
// the MPU-6050 IMU — this board wires SDA to GPIO21 and SCL to GPIO22.
#define I2C_SDA_PIN               21
#define I2C_SCL_PIN               22

// Dump-gate servo is on a PCA9685 PWM driver board, not a direct GPIO — leaves
// GPIO pins free and gives the servo its own dedicated ~50Hz PWM generator
// instead of sharing an ESP32 LEDC channel with other PWM users.
#define PCA9685_I2C_ADDR       0x40
#define PCA9685_PWM_FREQ_HZ      50   // hobby servos expect ~50Hz
#define ARM_SERVO_CHANNEL         0   // PCA9685 output channel driving the dump-gate servo

// MPU-6050 terrain-safety IMU — see terrain_monitor.py (STOP_IMU channel).
// Scale factors are for the library's power-on defaults: ±2g accel, ±250°/s gyro.
#define MPU6050_I2C_ADDR       0x68   // AD0 tied LOW; 0x69 if tied HIGH
#define IMU_ACCEL_LSB_PER_G  16384.0f
#define IMU_GYRO_LSB_PER_DPS   131.0f
#define GRAVITY_MSS              9.81f
#define IMU_PUBLISH_INTERVAL_MS   10   // 100Hz, matches terrain_monitor's calibration window

#define ARM_ACT_SPEED        200   // 0-255 PWM — placeholder, tune once actuator specs are known
// No limit switches — these are the sole stop mechanism for the actuator
// stroke. TODO(partner): measure real full-travel time on the bench and set
// these a little above it (enough margin to guarantee full extend/retract,
// not so much that the actuator stalls against its end stop for a long time).
#define ARM_LIFT_TIME_MS     3000
#define ARM_LOWER_TIME_MS    3000

#define ARM_SERVO_HOME_DEG      0   // TODO(partner): calibrate against the real dump-gate geometry
#define ARM_SERVO_DUMP_DEG    120
#define ARM_SERVO_PULSE_MIN_US 500  // pulse width at 0 degrees — TODO(partner): tune to the servo's real range
#define ARM_SERVO_PULSE_MAX_US 2400 // pulse width at 180 degrees
#define ARM_SERVO_MOVE_MS     600   // time to let the servo finish travelling before continuing
#define ARM_SERVO_HOLD_MS     500   // how long to hold at the dump angle before returning home

// ─── ULTRASONIC CONSTANTS ───
// HC-SR04 datasheet range is 2cm-4m with a ~15° detection cone.
#define ULTRASONIC_TIMEOUT_US       30000   // ~5m round trip @343m/s; abandon the read if no echo
#define ULTRASONIC_MIN_RANGE_M         0.02f
#define ULTRASONIC_MAX_RANGE_M         4.0f
#define ULTRASONIC_FIELD_OF_VIEW_RAD   0.26f   // ~15 degrees
#define ULTRASONIC_DETECT_THRESHOLD_CM 30.0f   // "object right in front" cutoff — tune on the bench
#define ULTRASONIC_READ_INTERVAL_MS   100      // 10Hz

// ─── micro-ROS objects ───
rcl_node_t node;
rclc_support_t support;
rcl_allocator_t allocator;
rclc_executor_t executor;

rcl_subscription_t cmd_vel_sub;
rcl_subscription_t estop_sub;
rcl_subscription_t arm_cmd_sub;
rcl_publisher_t odom_pub;
rcl_publisher_t motor_events_pub;
rcl_publisher_t arm_events_pub;
rcl_publisher_t imu_pub;
rcl_publisher_t ultrasonic_pub;
rcl_publisher_t obstacle_events_pub;

geometry_msgs__msg__Twist cmd_vel_msg;
std_msgs__msg__String estop_msg;
nav_msgs__msg__Odometry odom_msg;
std_msgs__msg__String motor_event_msg;
std_msgs__msg__String arm_cmd_msg;
std_msgs__msg__String arm_event_msg;
sensor_msgs__msg__Imu imu_msg;
sensor_msgs__msg__Range range_msg;
std_msgs__msg__String obstacle_event_msg;

Adafruit_PWMServoDriver pca = Adafruit_PWMServoDriver(PCA9685_I2C_ADDR);
MPU6050 imu(MPU6050_I2C_ADDR);

// ─── Shared state with mutex ───
portMUX_TYPE mux = portMUX_INITIALIZER_UNLOCKED;
float target_left  = 0.0f;
float target_right = 0.0f;
bool  estop        = false;
volatile long enc_left  = 0;
volatile long enc_right = 0;
volatile unsigned long last_cmd_vel_ms = 0;
volatile bool arm_trigger_pickup = false;
volatile bool object_detected = false;   // true when something is within ULTRASONIC_DETECT_THRESHOLD_CM

// ─── Odometry state ───
float odom_x     = 0.0f;
float odom_y     = 0.0f;
float odom_theta = 0.0f;

// ─── Encoder ISRs ───
void IRAM_ATTR enc_left_isr() {
    if (digitalRead(ENC_L_B) == LOW)
        enc_left++;
    else
        enc_left--;
}

void IRAM_ATTR enc_right_isr() {
    if (digitalRead(ENC_R_B) == LOW)
        enc_right++;
    else
        enc_right--;
}

// ─── PID ───
static float pid_compute(PIDState& s, float target, float actual) {
    float error  = target - actual;
    float i_term = s.integral + error * MOTOR_TASK_DT;
    // Anti-windup: clamp the integral so Ki·integral stays within ±INT_LIMIT PWM
    s.integral   = constrain(i_term, -PID_INT_LIMIT / PID_KI, PID_INT_LIMIT / PID_KI);
    float d_term = (error - s.prev_error) / MOTOR_TASK_DT;
    s.prev_error = error;
    return PID_KP * error + PID_KI * s.integral + PID_KD * d_term;
}

// ─── cmd_vel callback ───
void cmd_vel_callback(const void* msg) {
    const geometry_msgs__msg__Twist* twist =
        (const geometry_msgs__msg__Twist*)msg;

    float linear  = twist->linear.x;
    float angular = twist->angular.z;

    portENTER_CRITICAL(&mux);
    target_left  = (linear - angular * WHEEL_BASE / 2.0f) / WHEEL_RADIUS;
    target_right = (linear + angular * WHEEL_BASE / 2.0f) / WHEEL_RADIUS;
    last_cmd_vel_ms = millis();
    portEXIT_CRITICAL(&mux);

    motor_event_msg.data.data = (char*)"CMD_VEL received";
    motor_event_msg.data.size = 16;
    rcl_publish(&motor_events_pub, &motor_event_msg, NULL);
}

// ─── estop callback ───
void estop_callback(const void* msg) {
    const std_msgs__msg__String* s = (const std_msgs__msg__String*)msg;
    // Coordinator sends "1" to cut motors, "0" to re-enable.
    bool active = (s->data.size > 0 && s->data.data[0] == '1');
    portENTER_CRITICAL(&mux);
    estop = active;
    if (active) {
        target_left  = 0.0f;
        target_right = 0.0f;
    }
    portEXIT_CRITICAL(&mux);
    if (active) {
        analogWrite(MOTOR_L_PWM, 0);
        analogWrite(MOTOR_R_PWM, 0);
    }
}

// ─── arm_cmd callback ───
// Coordinator/mission_fsm sends "PICKUP" to run the lift-dump-lower sequence.
void arm_cmd_callback(const void* msg) {
    const std_msgs__msg__String* s = (const std_msgs__msg__String*)msg;
    if (s->data.size >= 6 && strncmp(s->data.data, "PICKUP", 6) == 0) {
        portENTER_CRITICAL(&mux);
        arm_trigger_pickup = true;
        portEXIT_CRITICAL(&mux);
    }
}

// ─── PCA9685 servo helper ───
static void arm_servo_write(int deg) {
    int pulse_us = map(deg, 0, 180, ARM_SERVO_PULSE_MIN_US, ARM_SERVO_PULSE_MAX_US);
    pca.writeMicroseconds(ARM_SERVO_CHANNEL, pulse_us);
}

static void publish_arm_event(const char* msg) {
    arm_event_msg.data.data = (char*)msg;
    arm_event_msg.data.size = strlen(msg);
    arm_event_msg.data.capacity = strlen(msg) + 1;
    rcl_publish(&arm_events_pub, &arm_event_msg, NULL);
}

static void publish_obstacle_event(const char* msg) {
    obstacle_event_msg.data.data = (char*)msg;
    obstacle_event_msg.data.size = strlen(msg);
    obstacle_event_msg.data.capacity = strlen(msg) + 1;
    rcl_publish(&obstacle_events_pub, &obstacle_event_msg, NULL);
}

// ─── Ultrasonic task — Core 0 ───
// Polls the HC-SR04 at ULTRASONIC_READ_INTERVAL_MS. pulseIn() blocks the
// calling task for up to ULTRASONIC_TIMEOUT_US, so this runs in its own
// low-priority task rather than inline in loop().
void ultrasonic_task(void* pvParameters) {
    pinMode(ULTRASONIC_TRIG_PIN, OUTPUT);
    pinMode(ULTRASONIC_ECHO_PIN, INPUT);
    digitalWrite(ULTRASONIC_TRIG_PIN, LOW);

    bool was_detected = false;

    while (true) {
        // 10us trigger pulse per HC-SR04 datasheet
        digitalWrite(ULTRASONIC_TRIG_PIN, LOW);
        delayMicroseconds(2);
        digitalWrite(ULTRASONIC_TRIG_PIN, HIGH);
        delayMicroseconds(10);
        digitalWrite(ULTRASONIC_TRIG_PIN, LOW);

        unsigned long echo_us = pulseIn(ULTRASONIC_ECHO_PIN, HIGH, ULTRASONIC_TIMEOUT_US);

        // echo_us == 0 means pulseIn timed out — no echo (out of range / no object)
        bool in_range = echo_us > 0;
        float distance_cm = echo_us / 58.0f;   // round-trip time -> cm

        bool detected = in_range && distance_cm <= ULTRASONIC_DETECT_THRESHOLD_CM;

        portENTER_CRITICAL(&mux);
        object_detected = detected;
        portEXIT_CRITICAL(&mux);

        if (detected != was_detected) {
            publish_obstacle_event(detected ? "OBSTACLE_DETECTED" : "OBSTACLE_CLEAR");
            was_detected = detected;
        }

        if (in_range) {
            range_msg.range = distance_cm / 100.0f;   // publish in meters
            rcl_publish(&ultrasonic_pub, &range_msg, NULL);
        }

        vTaskDelay(pdMS_TO_TICKS(ULTRASONIC_READ_INTERVAL_MS));
    }
}

// ─── Arm task — Core 0 ───
// Non-PID: the actuator sequence is open-loop (time-bounded, no position
// feedback), so it doesn't need the tight 100Hz loop the drivetrain does.
void arm_task(void* pvParameters) {
    arm_servo_write(ARM_SERVO_HOME_DEG);

    pinMode(ARM_ACT_PWM, OUTPUT);
    pinMode(ARM_ACT_DIR, OUTPUT);
    analogWrite(ARM_ACT_PWM, 0);

    while (true) {
        bool trigger;
        portENTER_CRITICAL(&mux);
        trigger = arm_trigger_pickup;
        arm_trigger_pickup = false;
        portEXIT_CRITICAL(&mux);

        if (trigger) {
            // 1. Lift
            digitalWrite(ARM_ACT_DIR, HIGH);
            analogWrite(ARM_ACT_PWM, ARM_ACT_SPEED);
            unsigned long start = millis();
            bool aborted = false;
            while (millis() - start < ARM_LIFT_TIME_MS) {
                portENTER_CRITICAL(&mux);
                aborted = estop;
                portEXIT_CRITICAL(&mux);
                if (aborted) break;
                vTaskDelay(pdMS_TO_TICKS(10));
            }
            analogWrite(ARM_ACT_PWM, 0);

            if (aborted) {
                publish_arm_event("ARM_ABORTED");
            } else {
                // 2. Dump
                arm_servo_write(ARM_SERVO_DUMP_DEG);
                vTaskDelay(pdMS_TO_TICKS(ARM_SERVO_MOVE_MS));
                vTaskDelay(pdMS_TO_TICKS(ARM_SERVO_HOLD_MS));
                arm_servo_write(ARM_SERVO_HOME_DEG);
                vTaskDelay(pdMS_TO_TICKS(ARM_SERVO_MOVE_MS));

                // 3. Lower back down
                digitalWrite(ARM_ACT_DIR, LOW);
                analogWrite(ARM_ACT_PWM, ARM_ACT_SPEED);
                start = millis();
                while (millis() - start < ARM_LOWER_TIME_MS) {
                    vTaskDelay(pdMS_TO_TICKS(10));
                }
                analogWrite(ARM_ACT_PWM, 0);

                publish_arm_event("ARM_DONE");
            }
        }

        vTaskDelay(pdMS_TO_TICKS(20));
    }
}

// ─── Motor task — Core 1 ───
void motor_task(void* pvParameters) {
    PIDState pid_l = {}, pid_r = {};
    long prev_enc_l = 0, prev_enc_r = 0;

    while (true) {
        float t_left, t_right;
        bool  e_stop;
        unsigned long last_cmd;

        portENTER_CRITICAL(&mux);
        t_left   = target_left;
        t_right  = target_right;
        e_stop   = estop;
        last_cmd = last_cmd_vel_ms;
        portEXIT_CRITICAL(&mux);

        // Measure actual wheel speed (rad/s) from encoder delta
        long curr_l = enc_left;
        long curr_r = enc_right;
        float actual_l = (curr_l - prev_enc_l) * RADS_PER_TICK / MOTOR_TASK_DT;
        float actual_r = (curr_r - prev_enc_r) * RADS_PER_TICK / MOTOR_TASK_DT;
        prev_enc_l = curr_l;
        prev_enc_r = curr_r;

        // Watchdog / e-stop: cut power and reset PID state
        if (millis() - last_cmd > 1000 || e_stop) {
            analogWrite(MOTOR_L_PWM, 0);
            analogWrite(MOTOR_R_PWM, 0);
            pid_l = {};
            pid_r = {};
            vTaskDelay(pdMS_TO_TICKS(10));
            continue;
        }

        // Left motor
        if (fabsf(t_left) < 0.01f) {
            analogWrite(MOTOR_L_PWM, 0);
            pid_l = {};
        } else {
            float out_l  = pid_compute(pid_l, t_left, actual_l);
            // Direction from target sign; PID magnitude drives PWM.
            // Negative out (overshoot) clamps to 0 (coast) rather than reversing.
            float drive_l = out_l * (t_left >= 0.0f ? 1.0f : -1.0f);
            digitalWrite(MOTOR_L_DIR, t_left >= 0.0f ? HIGH : LOW);
            analogWrite(MOTOR_L_PWM, (int)constrain(drive_l, 0.0f, 255.0f));
        }

        // Right motor
        if (fabsf(t_right) < 0.01f) {
            analogWrite(MOTOR_R_PWM, 0);
            pid_r = {};
        } else {
            float out_r   = pid_compute(pid_r, t_right, actual_r);
            float drive_r = out_r * (t_right >= 0.0f ? 1.0f : -1.0f);
            digitalWrite(MOTOR_R_DIR, t_right >= 0.0f ? LOW : HIGH);
            analogWrite(MOTOR_R_PWM, (int)constrain(drive_r, 0.0f, 255.0f));
        }

        vTaskDelay(pdMS_TO_TICKS(10));
    }
}

// ─── setup ───
void setup() {
    Serial.begin(115200);
    set_microros_transports();

    // Motor pins
    pinMode(MOTOR_L_PWM, OUTPUT);
    pinMode(MOTOR_L_DIR, OUTPUT);
    pinMode(MOTOR_R_PWM, OUTPUT);
    pinMode(MOTOR_R_DIR, OUTPUT);

    // Start motors off
    analogWrite(MOTOR_L_PWM, 0);
    analogWrite(MOTOR_R_PWM, 0);

    // Encoders
    pinMode(ENC_L_A, INPUT);
    pinMode(ENC_L_B, INPUT);
    attachInterrupt(digitalPinToInterrupt(ENC_L_A), enc_left_isr, RISING);
    pinMode(ENC_R_A, INPUT);
    pinMode(ENC_R_B, INPUT);
    attachInterrupt(digitalPinToInterrupt(ENC_R_A), enc_right_isr, RISING);

    // Shared I2C bus — PCA9685 (arm dump-gate servo) + MPU-6050 (terrain IMU)
    Wire.begin(I2C_SDA_PIN, I2C_SCL_PIN);

    pca.begin();
    pca.setPWMFreq(PCA9685_PWM_FREQ_HZ);

    imu.initialize();
    if (!imu.testConnection()) {
        Serial.println("MPU6050 init failed — check wiring/address");
    }
    // Fields that never change: no orientation estimate (raw accel/gyro only),
    // so mark those covariances unknown per REP-145.
    imu_msg.header.frame_id.data     = (char*)"imu";
    imu_msg.header.frame_id.size     = 3;
    imu_msg.header.frame_id.capacity = 4;
    imu_msg.orientation.w                    = 1.0;
    imu_msg.orientation_covariance[0]        = -1.0;
    imu_msg.angular_velocity_covariance[0]   = -1.0;
    imu_msg.linear_acceleration_covariance[0] = -1.0;

    // Fields that never change across reads
    range_msg.header.frame_id.data     = (char*)"ultrasonic";
    range_msg.header.frame_id.size     = 10;
    range_msg.header.frame_id.capacity = 11;
    range_msg.radiation_type = sensor_msgs__msg__Range__ULTRASOUND;
    range_msg.field_of_view  = ULTRASONIC_FIELD_OF_VIEW_RAD;
    range_msg.min_range      = ULTRASONIC_MIN_RANGE_M;
    range_msg.max_range      = ULTRASONIC_MAX_RANGE_M;

    // micro-ROS init
    allocator = rcl_get_default_allocator();
    rclc_support_init(&support, 0, NULL, &allocator);
    rclc_node_init_default(&node, "esp32_controller", "", &support);

    // Subscriptions
    rclc_subscription_init_default(&cmd_vel_sub, &node,
        ROSIDL_GET_MSG_TYPE_SUPPORT(geometry_msgs, msg, Twist),
        "/cmd_vel");
    rclc_subscription_init_default(&estop_sub, &node,
        ROSIDL_GET_MSG_TYPE_SUPPORT(std_msgs, msg, String),
        "/e_stop");
    rclc_subscription_init_default(&arm_cmd_sub, &node,
        ROSIDL_GET_MSG_TYPE_SUPPORT(std_msgs, msg, String),
        "/arm_cmd");

    // Publishers
    rclc_publisher_init_default(&odom_pub, &node,
        ROSIDL_GET_MSG_TYPE_SUPPORT(nav_msgs, msg, Odometry),
        "/wheel/odometry");
    rclc_publisher_init_default(&motor_events_pub, &node,
        ROSIDL_GET_MSG_TYPE_SUPPORT(std_msgs, msg, String),
        "/motor_events");
    rclc_publisher_init_default(&arm_events_pub, &node,
        ROSIDL_GET_MSG_TYPE_SUPPORT(std_msgs, msg, String),
        "/arm_events");
    rclc_publisher_init_default(&imu_pub, &node,
        ROSIDL_GET_MSG_TYPE_SUPPORT(sensor_msgs, msg, Imu),
        "/imu/data");
    rclc_publisher_init_default(&ultrasonic_pub, &node,
        ROSIDL_GET_MSG_TYPE_SUPPORT(sensor_msgs, msg, Range),
        "/ultrasonic/range");
    rclc_publisher_init_default(&obstacle_events_pub, &node,
        ROSIDL_GET_MSG_TYPE_SUPPORT(std_msgs, msg, String),
        "/obstacle_events");

    // Executor
    rclc_executor_init(&executor, &support.context, 3, &allocator);
    rclc_executor_add_subscription(&executor, &cmd_vel_sub, &cmd_vel_msg,
        &cmd_vel_callback, ON_NEW_DATA);
    rclc_executor_add_subscription(&executor, &estop_sub, &estop_msg,
        &estop_callback, ON_NEW_DATA);
    rclc_executor_add_subscription(&executor, &arm_cmd_sub, &arm_cmd_msg,
        &arm_cmd_callback, ON_NEW_DATA);

    // Pin motor task to Core 1, arm + ultrasonic tasks to Core 0 (mostly idle in vTaskDelay)
    xTaskCreatePinnedToCore(motor_task, "MOTOR", 4096, NULL, 1, NULL, 1);
    xTaskCreatePinnedToCore(arm_task, "ARM", 4096, NULL, 1, NULL, 0);
    xTaskCreatePinnedToCore(ultrasonic_task, "ULTRASONIC", 2048, NULL, 1, NULL, 0);
}

// ─── loop — Core 0 ───
void loop() {
    rclc_executor_spin_some(&executor, RCL_MS_TO_NS(10));

    static unsigned long last_imu = 0;
    if (millis() - last_imu > IMU_PUBLISH_INTERVAL_MS) {
        last_imu = millis();

        int16_t ax, ay, az, gx, gy, gz;
        imu.getMotion6(&ax, &ay, &az, &gx, &gy, &gz);

        // TODO(partner): mounting orientation isn't calibrated yet — flat
        // ground should read az ≈ +GRAVITY_MSS (terrain_monitor's atan2(ax, az)
        // pitch convention assumes this). Re-check axis signs once mounted.
        imu_msg.linear_acceleration.x = (ax / IMU_ACCEL_LSB_PER_G) * GRAVITY_MSS;
        imu_msg.linear_acceleration.y = (ay / IMU_ACCEL_LSB_PER_G) * GRAVITY_MSS;
        imu_msg.linear_acceleration.z = (az / IMU_ACCEL_LSB_PER_G) * GRAVITY_MSS;
        imu_msg.angular_velocity.x = (gx / IMU_GYRO_LSB_PER_DPS) * DEG_TO_RAD;
        imu_msg.angular_velocity.y = (gy / IMU_GYRO_LSB_PER_DPS) * DEG_TO_RAD;
        imu_msg.angular_velocity.z = (gz / IMU_GYRO_LSB_PER_DPS) * DEG_TO_RAD;

        rcl_publish(&imu_pub, &imu_msg, NULL);
    }

    static unsigned long last_odom = 0;
    if (millis() - last_odom > 100) {
        last_odom = millis();

        static long last_enc_l = 0;
        static long last_enc_r = 0;
        long curr_l = enc_left;
        long curr_r = enc_right;
        float dl = (curr_l - last_enc_l) * METERS_PER_TICK;
        float dr = (curr_r - last_enc_r) * METERS_PER_TICK;
        last_enc_l = curr_l;
        last_enc_r = curr_r;

        float ds     = (dl + dr) / 2.0f;
        float dtheta = (dr - dl) / WHEEL_BASE;
        odom_theta  += dtheta;
        odom_x      += ds * cosf(odom_theta);
        odom_y      += ds * sinf(odom_theta);

        odom_msg.pose.pose.position.x    = odom_x;
        odom_msg.pose.pose.position.y    = odom_y;
        odom_msg.pose.pose.orientation.w = cosf(odom_theta / 2.0f);
        odom_msg.pose.pose.orientation.x = 0.0f;
        odom_msg.pose.pose.orientation.y = 0.0f;
        odom_msg.pose.pose.orientation.z = sinf(odom_theta / 2.0f);

        rcl_publish(&odom_pub, &odom_msg, NULL);
    }
}

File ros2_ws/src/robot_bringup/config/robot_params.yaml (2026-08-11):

# Tunable parameters for all Autonomous Beach Robot nodes.
# Values here are applied at launch; override any individual param via
# ros2 launch robot_bringup beach_robot.launch.py <arg>:=<value>

trash_detector:
  ros__parameters:
    # model_path is set from the launch argument — not hardcoded here.
    confidence_threshold: 0.35  # raise to ~0.35 for field use; lowered for testing
    yolo_interval: 0.1          # seconds between YOLO calls (~10 fps)
    frame_width: 640
    frame_height: 480

terrain_monitor:
  ros__parameters:
    pitch_threshold: 0.15       # rad (~8.6°) — tune if false positives on slopes
    vibration_multiplier: 2.5   # variance above baseline triggers STOP_IMU
    sand_ratio_threshold: 0.5   # fraction of bottom-ROI that must be sand — CALIBRATE ON-SITE
    hsv_lower: [10, 20, 150]    # HSV lower bound for sand colour — CALIBRATE ON-SITE
    hsv_upper: [25, 255, 255]   # HSV upper bound for sand colour — CALIBRATE ON-SITE
    sim_mode: false              # set true via sim.launch.py — suppresses terrain events
    disable_imu_safety: false    # set true to mute STOP_IMU (indoor/desk testing)
    disable_camera_safety: false # set true to mute STOP_CAM (no sand in view)

mission_fsm:
  ros__parameters:
    kp: 0.002                   # visual servo gain: angular_z = -kp * pixel_error
    approach_speed: 0.2         # m/s forward speed in TRACK state
    scan_angular_speed: 0.3     # rad/s rotation rate in SCAN state
    pickup_area_threshold: 0.15 # normalised bbox area (bbox_px/frame_px) → PICKUP
    detection_conf_threshold: 0.35
    track_loss_timeout: 2.5     # seconds of silence before TRACK → SCAN fallback
    calibrate_duration: 1.5     # seconds to hold still in CALIBRATE
    stuck_timeout: 5.0          # seconds of no odometry movement before STUCK
    battery_cutoff_voltage: 10.5  # 3S LiPo hard cutoff (10.5 V = 3.5 V/cell)
    frame_width: 640
    frame_height: 480
    sim_mode: false              # set true when running with fake_hardware.py (disables STUCK watchdog)
    # csv_log_path is set from the launch argument — not hardcoded here.

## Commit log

2026-06-05 add trained model, results, updated gitignore
    [results.csv]
2026-06-10 Mission control and RobotBringup nodes written
    [robot_params.yaml]
2026-06-10 Created hardware simulation to test without hardware
    [robot_params.yaml]
2026-06-17 Added simulation mode and fixed bugs in hardware-less simulations
    [robot_params.yaml]
2026-06-18 retrain on TACO+Roboflow: mAP50=0.584, confirmed 0.896 conf on real trash
    [results.csv]
2026-06-18 Added ability to disable safety measures for simulation
    [robot_params.yaml]
2026-06-24 Added camera stream for testing
2026-06-24 Track model files with Git LFS
2026-06-24 Added disable odometry for testing
2026-06-26 Fixed bug in camera_node
2026-06-29 Added main.cpp without PID
2026-06-30 Updated firmware to include odometry timestamps, final pin assignments
2026-06-30 Added PID to main.cpp. Fixed odometry bug in FSM
    [main.cpp]
2026-07-06 Compilation errors in main.cpp fixed
    Perfboard complete - physical testing ready to be started
    [main.cpp]
2026-07-06 Add core beach cleaning robot KiCad layout and schematic files. PCB design still needs to be finished
    [BeachRobot.kicad_pcb, BeachRobot.kicad_sch]
2026-07-24 Updated firmware to match real hardware assignments
    [robot_params.yaml]
2026-07-31 Create cad
2026-08-01 Updated naming for CAD files
    [arm.SLDPRT, axle.SLDPRT, bar.SLDPRT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]
2026-08-03 Outline firmware for arm
2026-08-04 Moved 'cad' into 'hardware' folder
    [arm.SLDPRT, axle.SLDPRT, bar.SLDPRT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]
2026-08-07 Updated pin assignments to match servo driver change
2026-08-18 Added sensor & object detection to firmware
2026-08-25 Revise README with comprehensive project details
    Updated project description, system architecture, and added detailed sections on perception pipeline, navigation, mission FSM, ESP32 firmware, hardware stack, repository structure, simulation, live c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
2026-08-25 Updated firmware pin definitions to match hardware
